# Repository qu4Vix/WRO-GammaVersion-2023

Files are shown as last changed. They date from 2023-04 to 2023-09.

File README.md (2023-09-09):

# WRO 2023 GammaVersion's
**GammaVersion's repo for WRO Future Engineers 2023 season**

***
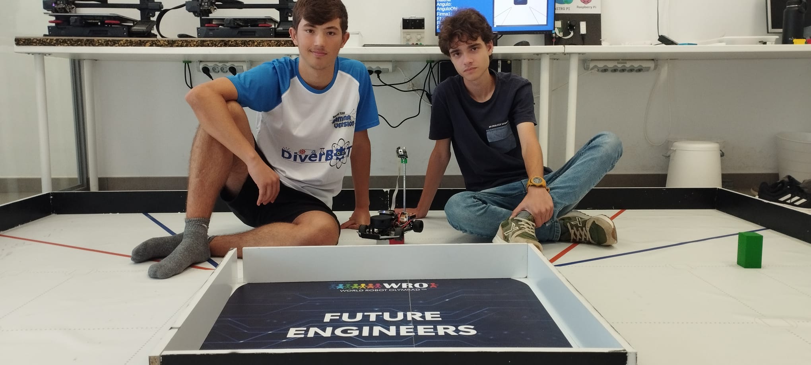
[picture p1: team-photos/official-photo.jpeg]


## Contents

* [Hardware](#hardware)
    * [Components](#component-list)
    * [Models](#models)
    * [Electronics](#electronics)
    * [Ackerman's](#ackerman-steering-geometry)

* [Software](#software)
    * [Sensors](#sensors)
    * [Position](#position)
    * [Strategy](#strategy)

* [Photos](#photos)
    * [Car images](#car-images)
    * [Team images](#team-images)

* [Videos](#videos)
    * [Demonstration videos](#demonstration-videos)

* [Legal](#legal)
    * [License](#license)
    * [Credits](#credits)

***

## Hardware
Building an autonomous car for this challenge involves a meticulous process of reimagining and redesigning various components to achieve precision, safety, and efficiency. In this project, we focused on enhancing the car's steering mechanism, designing a custom-printed circuit board (PCB) to connect all the components seamlessly, and implementing Light Detection and Ranging (LiDAR) technology for superior distance measurement compared to traditional ultrasonic sensors.

### Component List
* **DOIT ESP32 DevKit V1 x2**
* **Pixy 2**
* **RPLIDAR A1 M8**
* **MPU 9250**
* **Pololu Magnetic Encoder**
* **DSM44 Servo**
* **RC Smart Car Chassis Kit** Includes a simple motor
* **Motor Driver x2**
* **Power Supply x3**
* **RGB LEDS**

### Models
**3D-Printed Supports and Structural Parts:**
As a crucial part of our project, we designed and 3D-printed custom supports to secure mechanical components and sensors. These supports ensured precise placement and minimized interference. Additionally, we utilized 3D printing to create lightweight yet robust structural components, allowing us to tailor the car's design to our specific needs while maintaining its strength and adaptability.
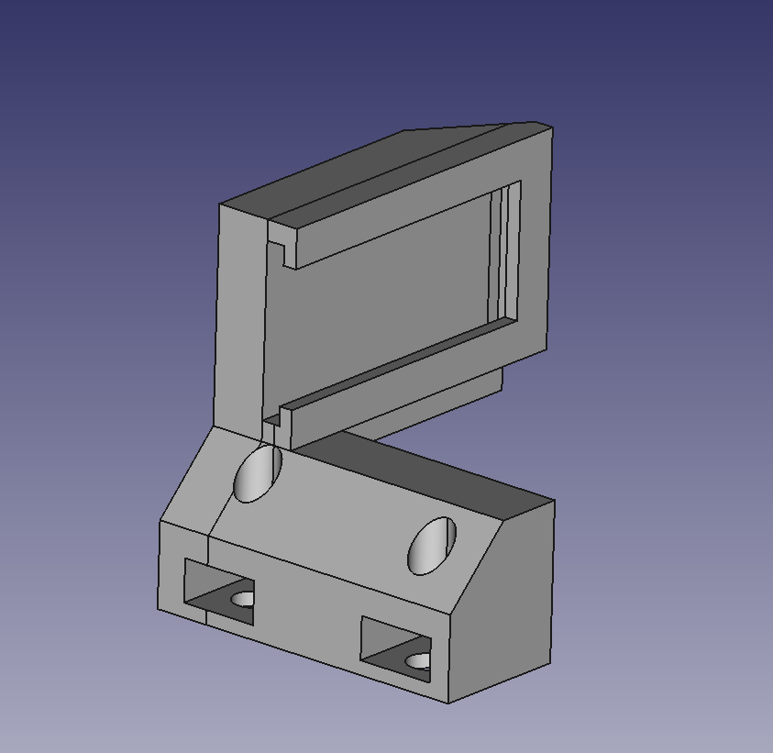
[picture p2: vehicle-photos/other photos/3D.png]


### Electronics
**LiDAR Implementation:**
Rather than relying on traditional ultrasonic sensors for obstacle detection, we opted for LiDAR technology. LiDAR, which stands for Light Detection and Ranging, uses laser beams to measure distances to objects with exceptional precision. This technology offers several advantages over ultrasonic sensors:

a. Greater Range: LiDAR can detect objects at much greater distances, providing the car with more time to react to potential obstacles.

b. High Precision: LiDAR provides accurate distance measurements, resulting in better navigation and collision avoidance.

c. 360-Degree Coverage: LiDAR offers a full 360-degree view around the car, ensuring comprehensive situational awareness.

d. Environmental Adaptability: LiDAR is less affected by environmental factors such as ambient light, making it more reliable in various conditions.
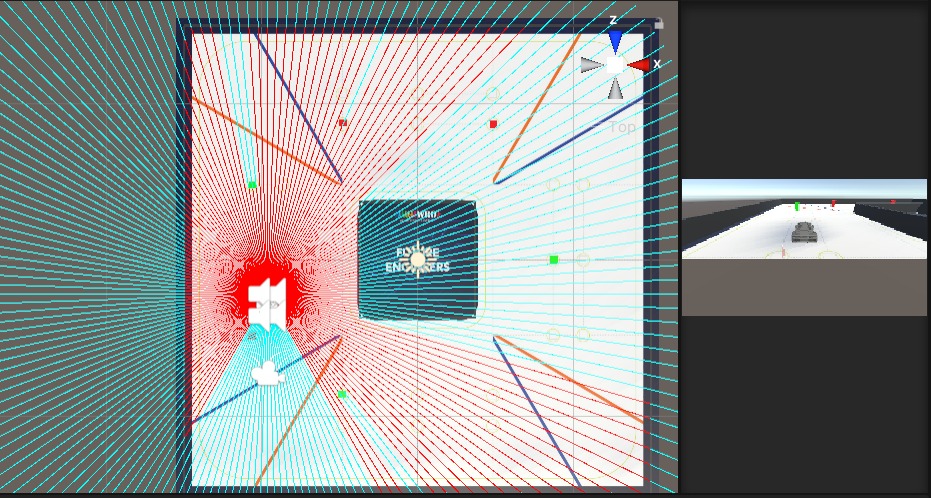
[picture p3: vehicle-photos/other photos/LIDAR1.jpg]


**Esp-32**
To bring our autonomous car project to fruition, we opted for the ESP-32 microcontroller as the central control unit. The ESP-32 boasts several compelling advantages that played a pivotal role in our decision-making process:

1. Computing Power and Versatility: The ESP-32 distinguishes itself with its robust computational capabilities and remarkable versatility. Equipped with a potent dual-core processor and ample memory capacity, it emerged as the natural choice for our robotics endeavor, enabling rapid computation and accommodating our storage needs seamlessly.

2. Advanced Wireless Connectivity: The ESP-32 integrates cutting-edge Wi-Fi and Bluetooth connectivity, positioning it as a frontrunner for efficient wireless communication. This capability empowered us to establish seamless and reliable communication channels between the autonomous car and external devices, such as remote controls or monitoring systems.

3. Sensor and Actuator Compatibility: The ESP-32's adaptability extends to sensor and actuator integration. With its multitude of I/O (input/output) pins and versatile interface options, we effortlessly connected and controlled various sensors, including the IMU and LiDAR, as well as the steering servos.
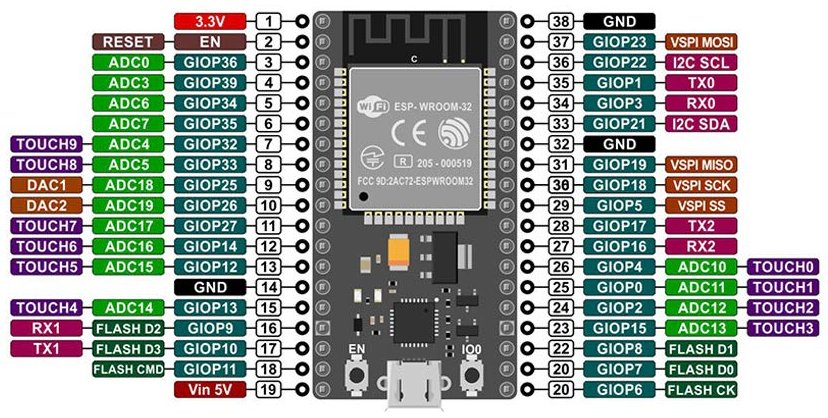
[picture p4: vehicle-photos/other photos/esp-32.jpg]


**Custom PCB Design:**
To seamlessly connect and control all the components of our autonomous car, we designed and printed a custom PCB. The PCB acted as the central hub that allowed us to interface with sensors, motors, microcontrollers, and other electronic components efficiently.

Our custom PCB design allowed for cleaner wiring, reduced interference, and enhanced reliability. It simplified the process of connecting and configuring various sensors and actuators, enabling smoother integration and troubleshooting during the development phase.
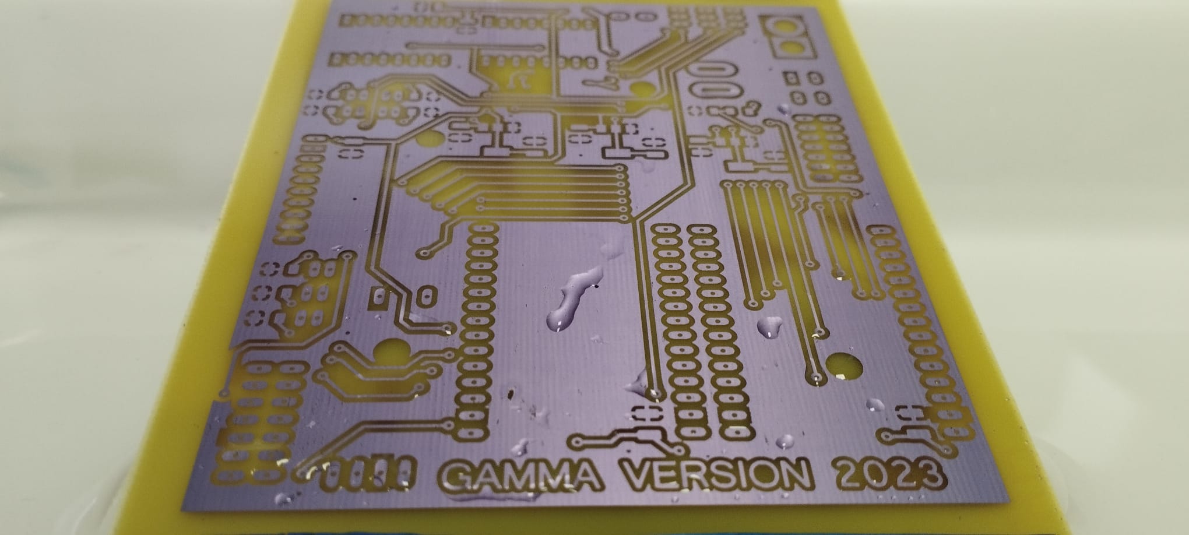
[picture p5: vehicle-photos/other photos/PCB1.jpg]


Our custom-designed PCB played a central role in integrating various components seamlessly. To ensure efficient power management and distribution, we implemented three distinct power sources:

a. Dual 5-Volt Power Supplies: One 5-volt power supply was dedicated to powering the LiDAR system, while the other supplied power to the steering servos. This separation of power sources allowed us to optimize the energy delivery to these critical components, ensuring their reliable operation.
<div calss ="row">
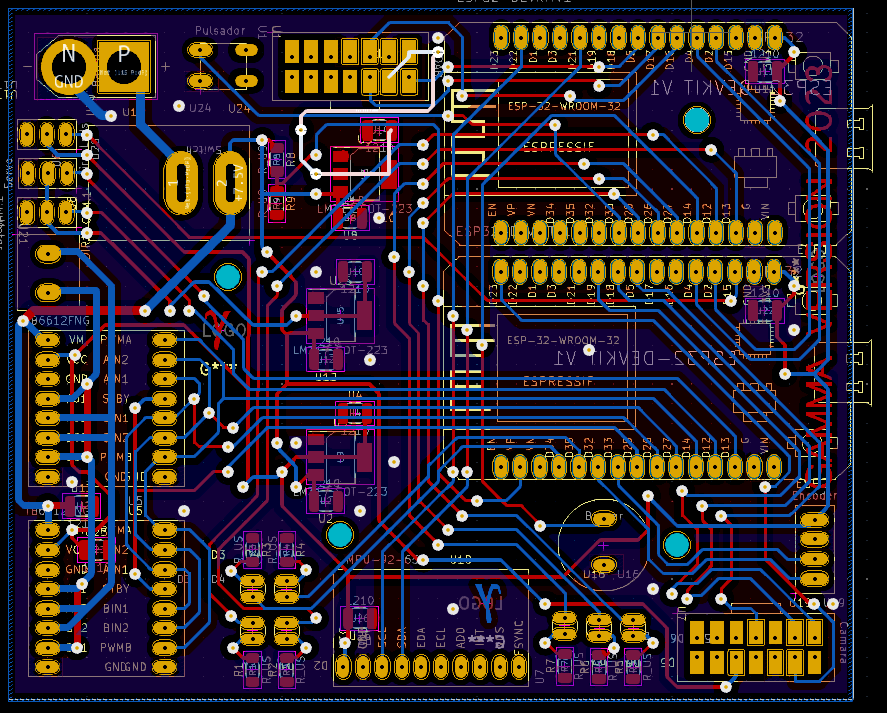
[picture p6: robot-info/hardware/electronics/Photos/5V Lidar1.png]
    
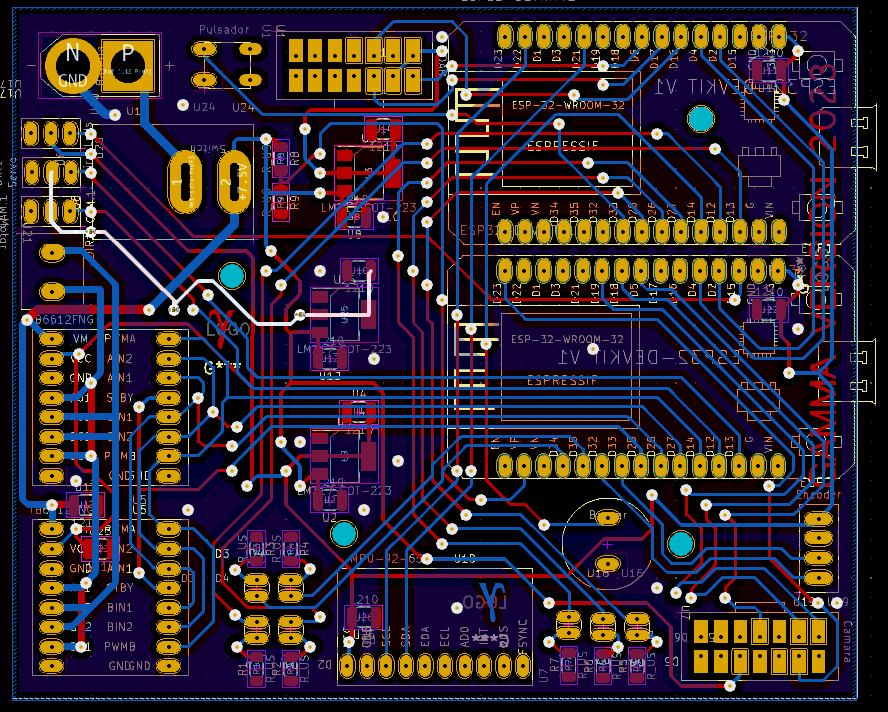
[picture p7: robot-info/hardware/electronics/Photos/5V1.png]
    
</div>

b. 3.3-Volt Power Supply: A dedicated 3.3-volt power supply was employed to energize the microcontrollers, IMU (Inertial Measurement Unit), motor drivers, and LED lights. This voltage level was carefully chosen to meet the requirements of these electronic components, guaranteeing stable and consistent performance.
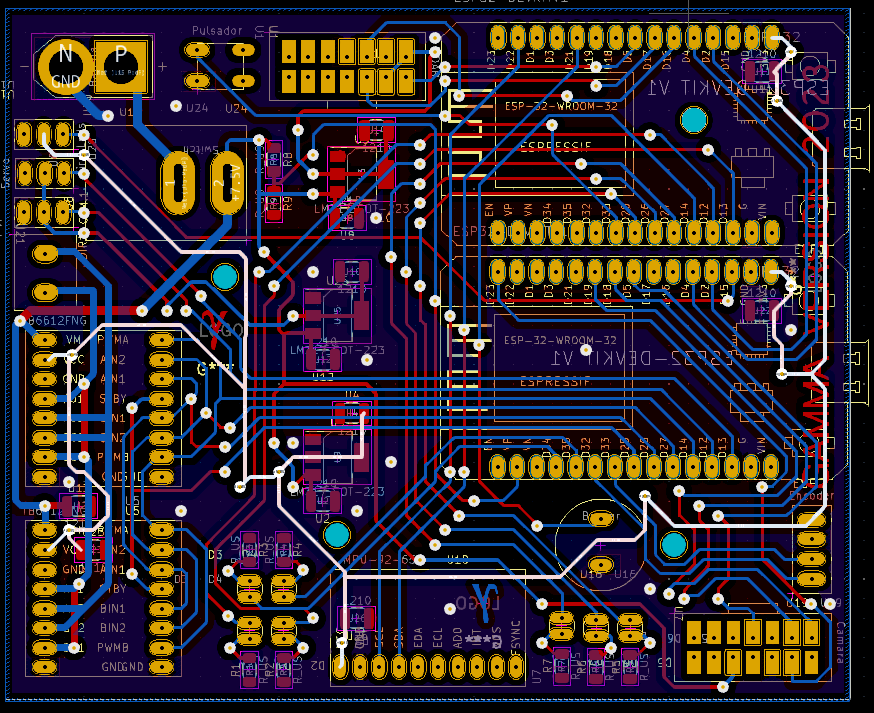
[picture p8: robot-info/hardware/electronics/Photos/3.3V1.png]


By employing these distinct power sources, we effectively managed the power needs of our autonomous car's various subsystems, ensuring that each component received the appropriate voltage and current for reliable operation. This meticulous power management contributed to the overall success and stability of our robotics project.

### Ackerman's Steering Geometry
One of the key aspects of our project was reimagining the steering system to achieve a reduced turn ratio. To accomplish this, we implemented Ackermann steering geometry. Ackermann steering geometry is a mechanism that ensures that all four wheels of the car track along different paths during a turn, reducing tire wear and enabling smoother and more precise turns.

By incorporating Ackermann steering, we were able to optimize the car's turning radius, allowing it to navigate tighter corners with ease. This was achieved by adjusting the angles of the wheels and their pivot points, ensuring that the inner and outer wheels followed distinct paths, greatly enhancing the car's maneuverability.
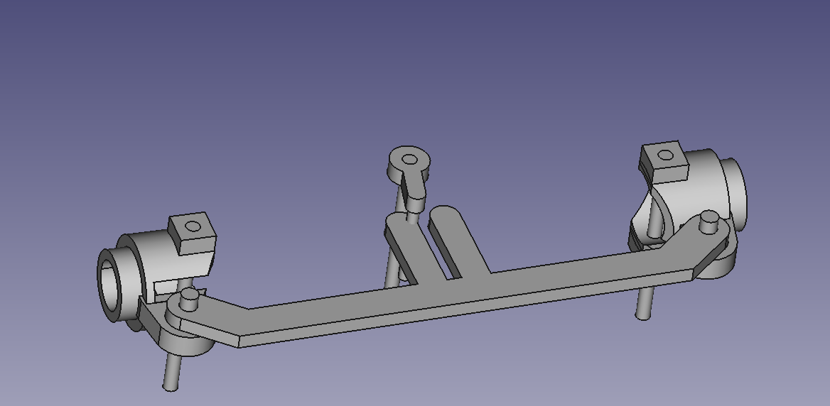
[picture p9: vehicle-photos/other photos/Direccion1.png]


***

## Software

### Sensors
* **MPU:** We use the MPU's GyroScope functionality to measure the angular speed along the Z-axis. Integrating this speed over time we get the orientation of the car.
* **Encoder:** The encoder allows us to know the displacement of the car and consequently its speed, which we regulate using a PID controller.
* **LIDAR:** The LIDAR sensor measures distances on a 360º range, therefore it allows the car to have a great knowledge of the surroundings. We store all the readings in an array when they are received.
* **Pixy 2:** Pixy is an intelligent camera which can identify regions with the same colour. As a result, our code to handle the detection of the traffic lights is very reduced. 

### Position
With the data of the orientation and the displacement of the car we are able to calculate the position of the car. This is worked out by integrating the displacement over the trajectory of the car. With these calculations the coordiante origin is set to the initial position of the car, but we change it to the bottom left corner of the playfield with the measures of the LIDAR.

### Strategy
Our strategy is to make the car able to define a path for the it to follow depending on the colour blocks it detects. We devide the playfield into eight sections, and the car stores whether it has to travel to the right or to the left in each section.

***

## Photos

### Car images
| | |
| --- | --- |
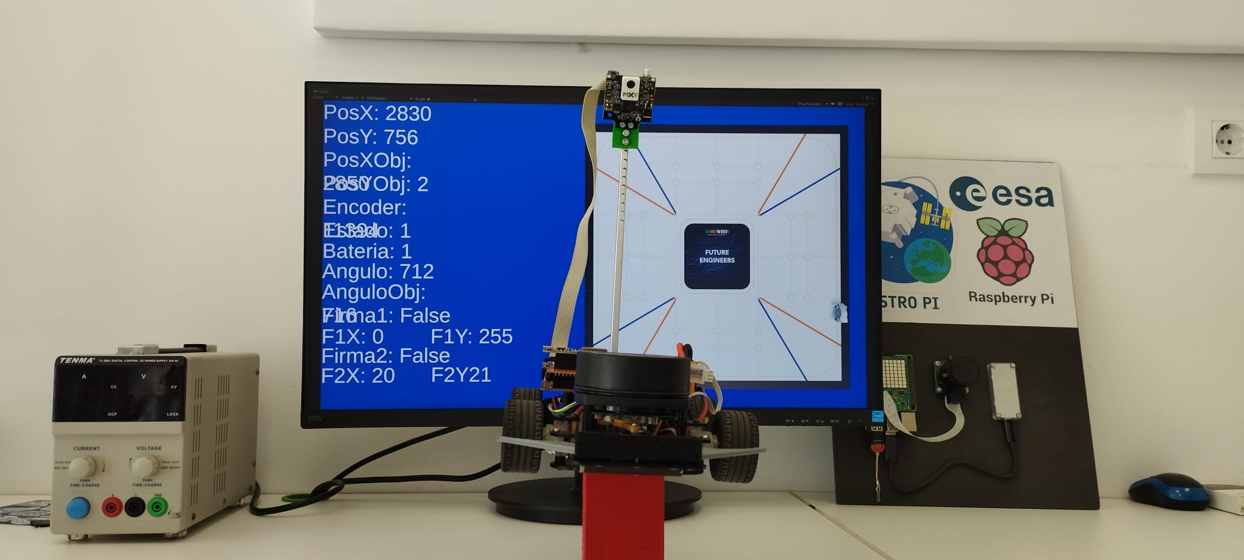
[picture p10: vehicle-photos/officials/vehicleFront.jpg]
front
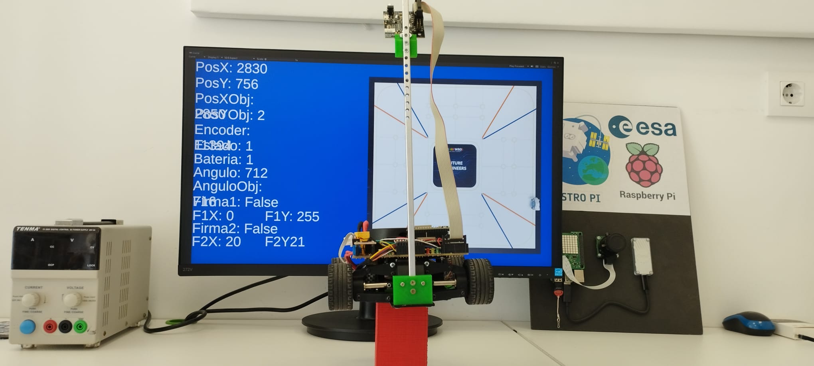
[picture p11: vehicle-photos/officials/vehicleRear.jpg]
back
|  |  |
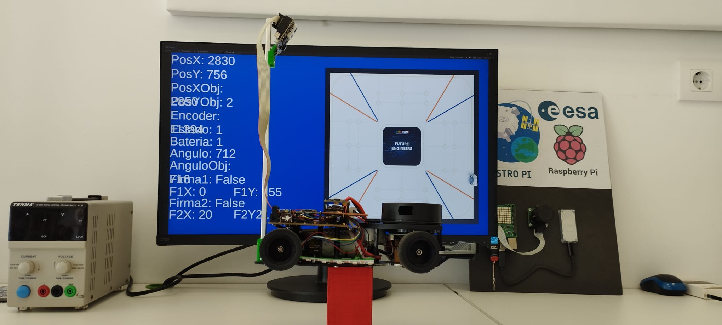
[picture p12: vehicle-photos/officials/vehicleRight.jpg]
right
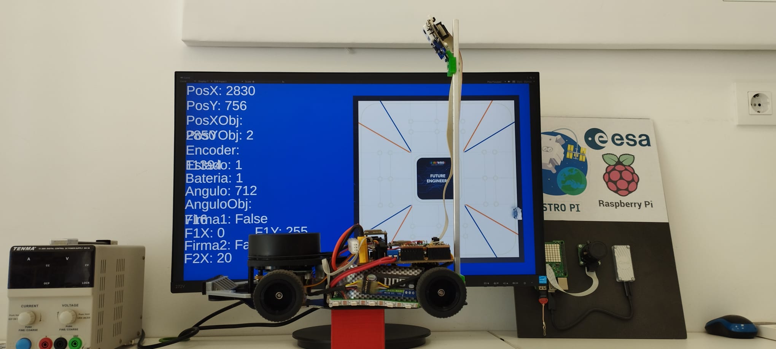
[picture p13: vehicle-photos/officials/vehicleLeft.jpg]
left
|  |  |
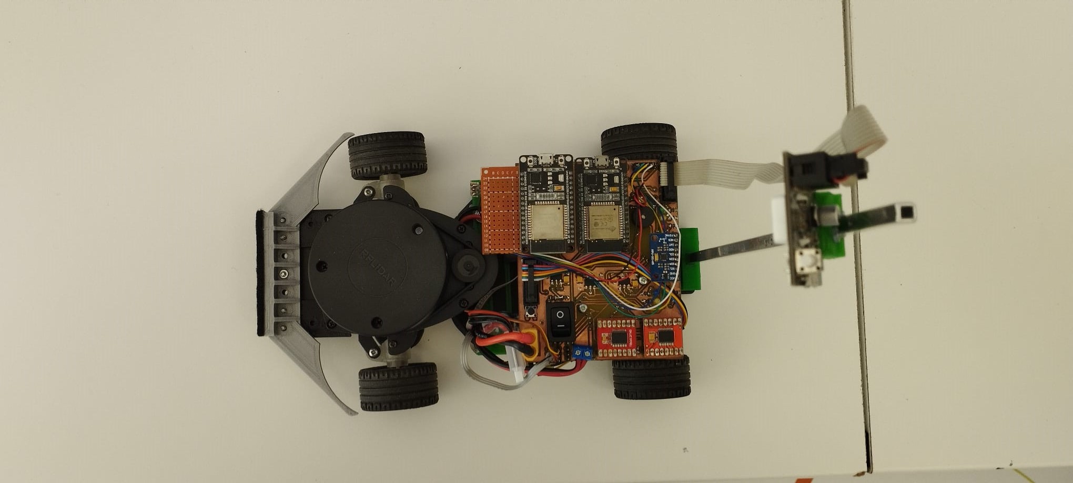
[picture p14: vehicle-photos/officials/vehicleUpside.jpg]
top
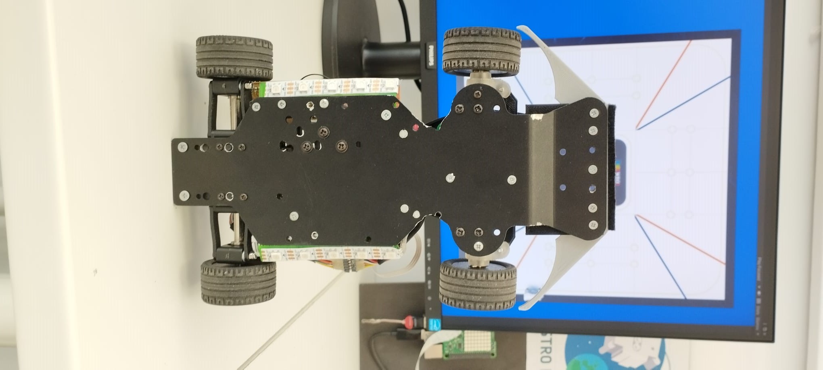
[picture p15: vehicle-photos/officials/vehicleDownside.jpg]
bottom
|  |  |

### Team images
| | |
| --- | --- |
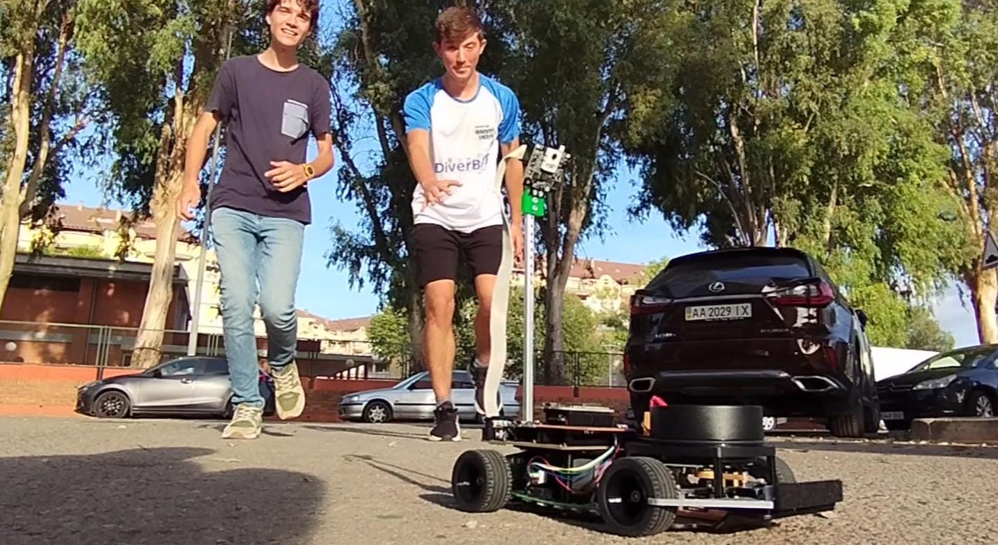
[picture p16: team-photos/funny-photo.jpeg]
funny
| official |  |

***

## Videos

### Demonstration videos

Demonstration videos of the car successfully completing both challenges.
The links to each of them can be found in:
* [Open Challenge](https://youtu.be/Oyp9x_MhnpQ?si=n7GRa3e0AN-YdxIk)
* [Obstacle Challenge](https://youtu.be/bCaAXYcNQ1c)

***

## Legal

### License

The [source code](/code/) in this repository is licensed under the **GNU General Public License v3.0**.

The [hardware](/robot-info/hardware/) exposed in this project is licensed under the **Creative Commons Attribution Share Alike 4.0 International** license.

The documentation of this repository; found in [`robot-info`](/robot-info/), [`vehicle-photos`](/vehicle-photos/), [`videos`](/videos/), [`team-photos`](/team-photos/), as well as this `README.md`; is licensed under the **CERN Open Hardware Licence Version 2 - Strongly Reciprocal** license.

A copy of each license can be found in the [LICENSE](LICENSE) file. More information about the licenses in the specific README.md of each section.

### Credits

***

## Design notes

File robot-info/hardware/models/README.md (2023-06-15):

### Models
In this folder you can find all the models used in our robot. All of them designed by us using Freecad.
***
### Supports
In the [supports](/supports/) folder, you can find all the supports made for hold diferent parts of the robot, such as sensors or the PCB.
***
### Steering
And the [steering](/steering/) folder, contains all the models used for the new steering system designed specialy for increase the steering angle.
***
### Freecad files
All the models are in .stl format, wich have large compatibility with 3d modeling progras and printing software. Also you have a Freecad folder in the [Supports](/supports/FreecadFiles/) and [Steering](/steering/FreecadFiles/) folders, in wich you can find the files to open in Freecad and edit easily all the models.

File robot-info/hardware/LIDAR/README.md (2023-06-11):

# LIDAR
## Explanatory directory for the LIDAR component

The [`frame_grabber.exe`](frame_grabber.exe) file is a testing program made by Slamtec with GPLv3 license which can be found in their [GitHub](https://github.com/Slamtec/rplidar_sdk) . No changes have been done to this file.

### Cable Color Code
- Yellow - TX
- Green - RX
- Orange - VCC
- White - GND
- Black - GND_Motor
- Blue - CTRL_Motor
- Red - 5V_Motor

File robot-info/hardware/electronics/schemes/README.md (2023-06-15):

## Schemes
### Folder Content
* **Union Diagram**: [This file](/UnionSchematic.pdf/), provides a graphical representation of all the necessary connections to properly assemble the robot. The union diagram will help you understand how the different components are connected and ensure that everything is properly interconnected.

* **Electrical Schematic**: [In this file](/PCBSchematic.pdf) you will find a detailed electrical diagram of the robot. This diagram provides a visual representation of how electrical components such as motors, sensors, microcontrollers, and power sources are connected. The electrical schematic is essential to understand how electrical current is distributed and flows within the robot.

***

### File format
All the files are in PDF format to ensure accurate and accessible viewing on different platforms and devices. You can use a PDF viewer to open and examine the diagrams in detail.

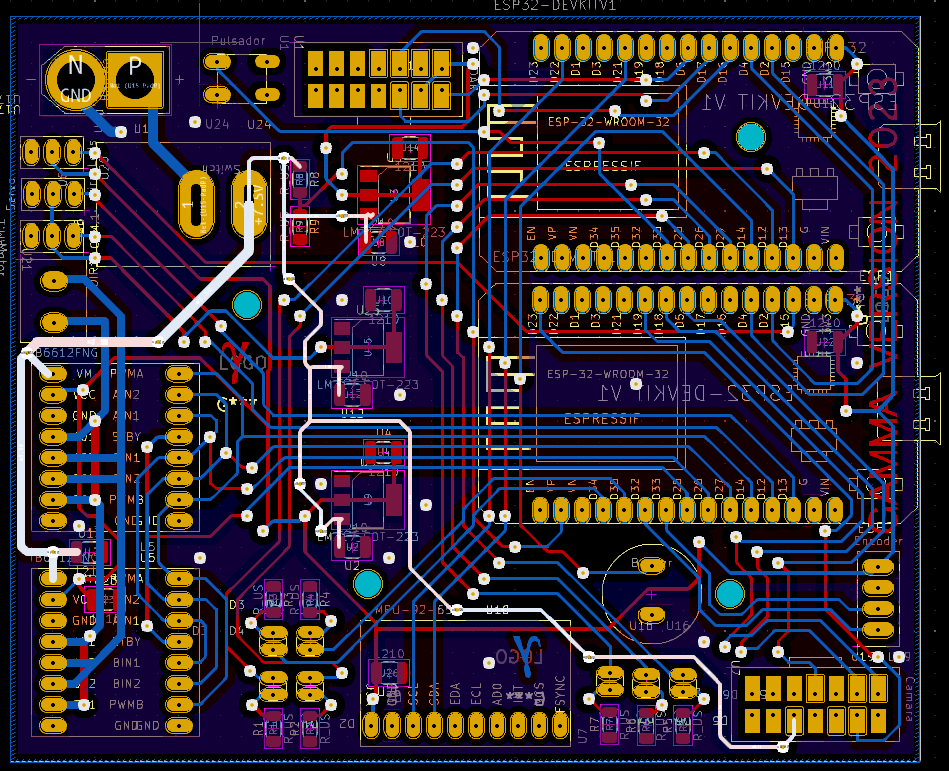
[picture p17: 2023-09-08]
robot-info/hardware/electronics/Photos/7V1.png

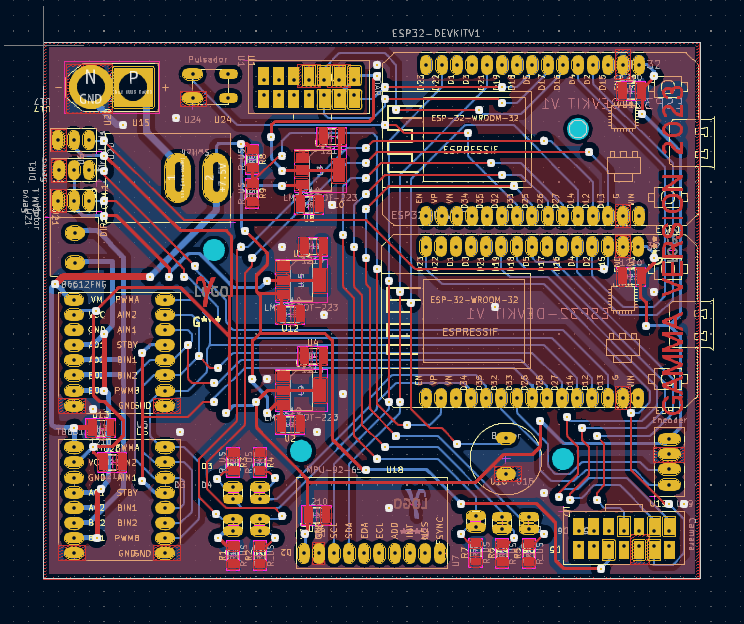
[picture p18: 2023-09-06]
robot-info/hardware/electronics/Photos/AllLayers.png

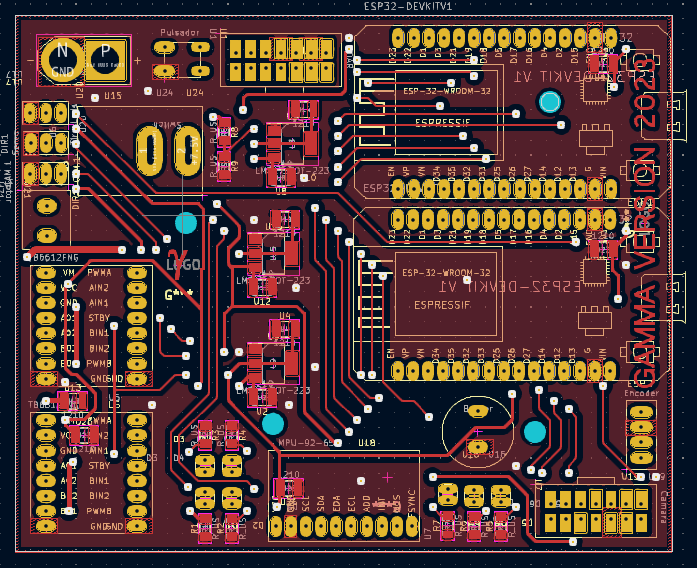
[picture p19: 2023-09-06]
robot-info/hardware/electronics/Photos/Layer1.png

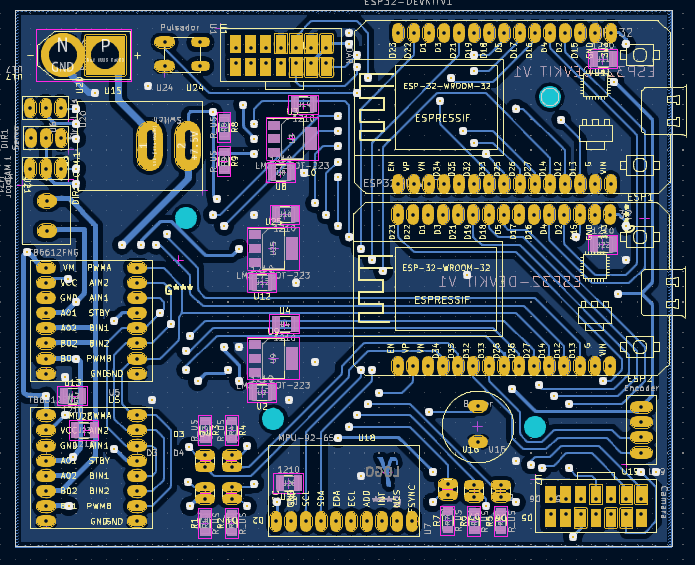
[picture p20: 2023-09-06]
robot-info/hardware/electronics/Photos/Layer2.png

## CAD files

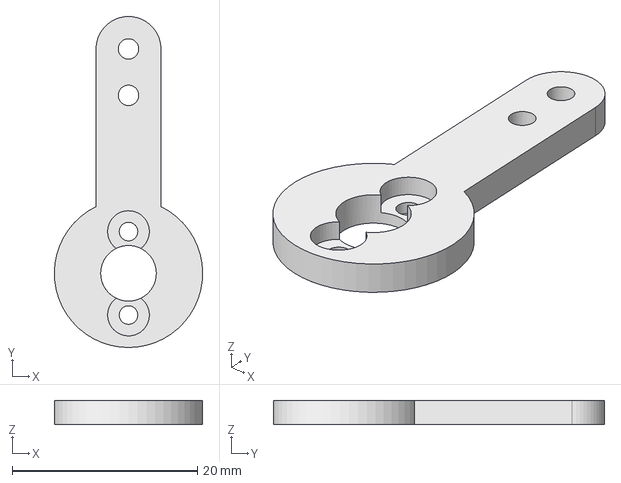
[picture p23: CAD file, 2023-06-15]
robot-info/hardware/models/steering/FreecadFiles/ServoArm.FCStd
16.0 x 35.7 x 2.60 mm

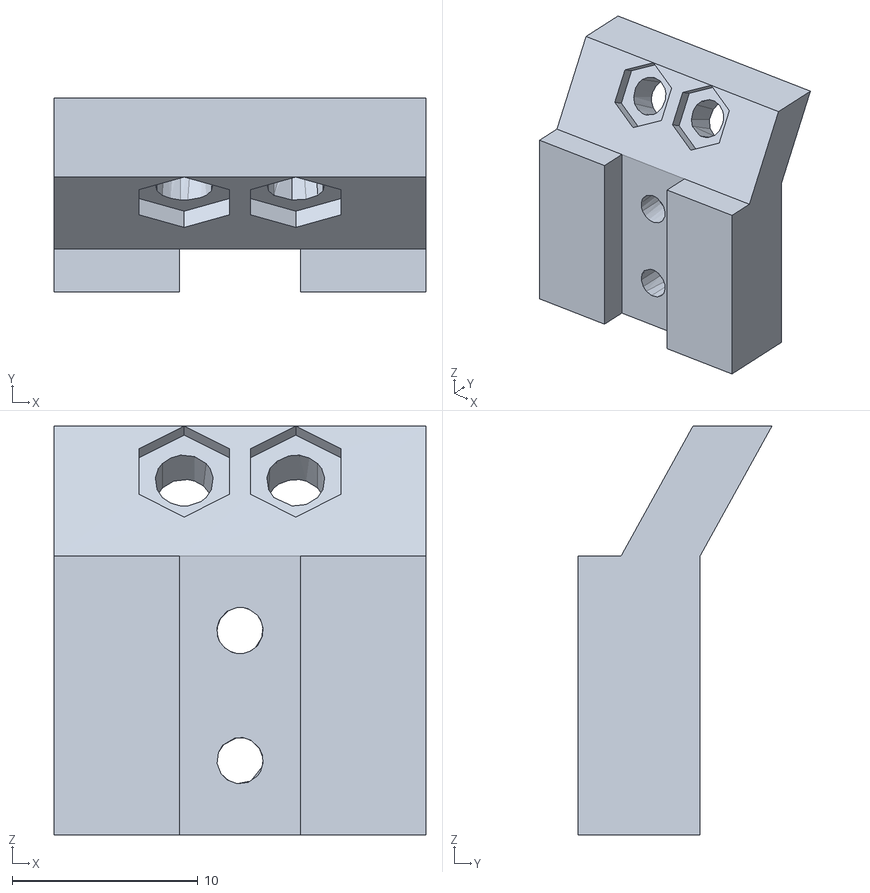
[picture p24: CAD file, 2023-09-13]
robot-info/hardware/models/supports/CameraSupport.stl
20.0 x 10.4 x 22.0

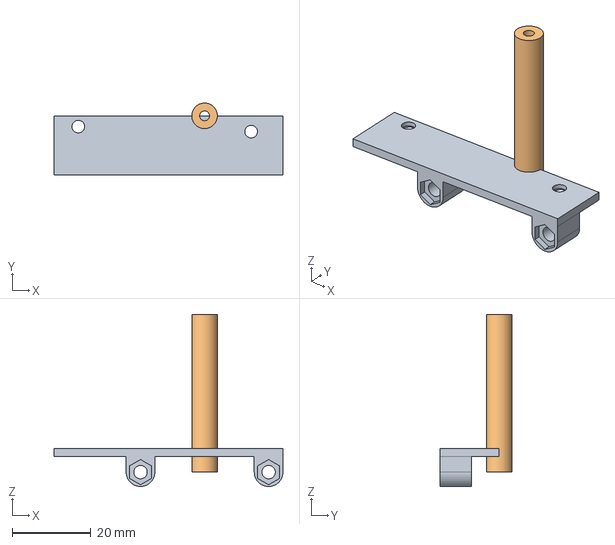
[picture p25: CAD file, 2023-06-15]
robot-info/hardware/models/supports/FreecadFiles/PcbSupports.FCStd
58.1 x 18.2 x 43.7 mm
Trasero
Delantero

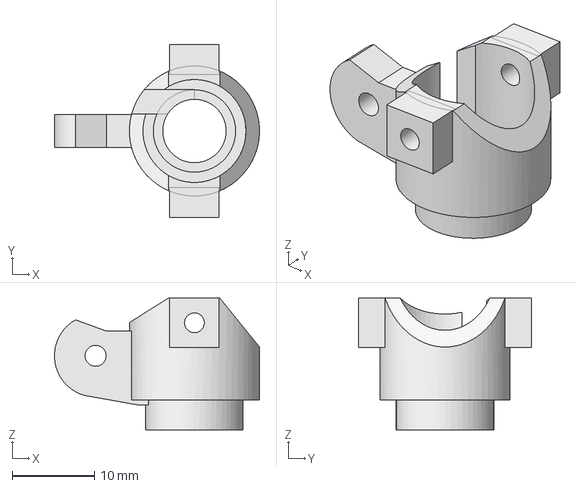
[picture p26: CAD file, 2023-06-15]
robot-info/hardware/models/steering/FreecadFiles/WheelHook.FCStd
24.9 x 21.0 x 16.0 mm

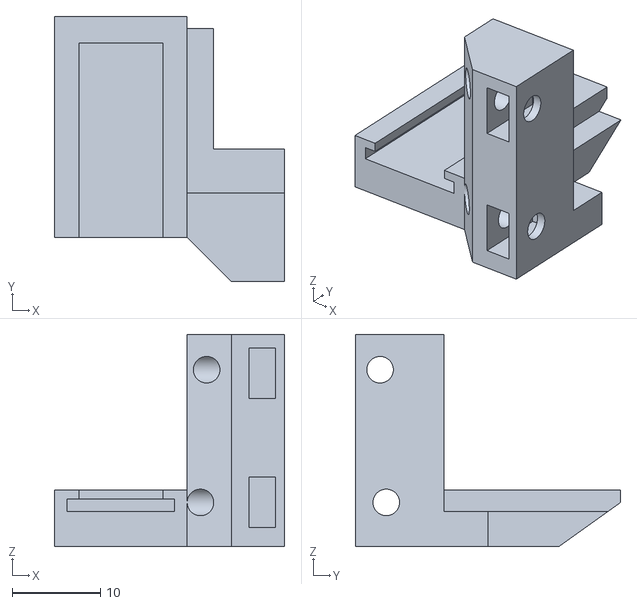
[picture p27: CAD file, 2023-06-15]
robot-info/hardware/models/supports/EncoderSupport-Base.stl
26.0 x 30.0 x 24.0

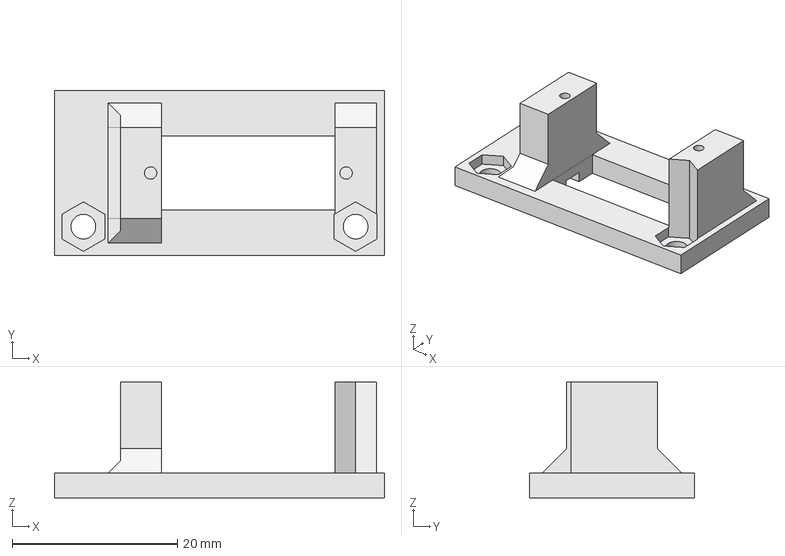
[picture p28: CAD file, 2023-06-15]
robot-info/hardware/models/supports/FreecadFiles/ServoSupport.FCStd
40.0 x 20.0 x 14.1 mm

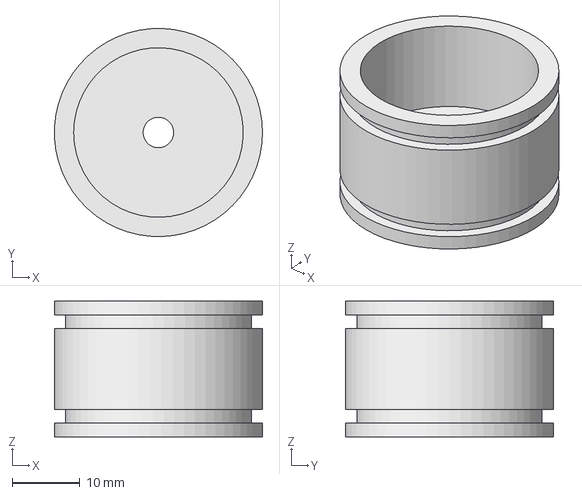
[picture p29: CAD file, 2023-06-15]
robot-info/hardware/models/steering/FreecadFiles/Wheel.FCStd
30.7 x 30.7 x 20.0 mm

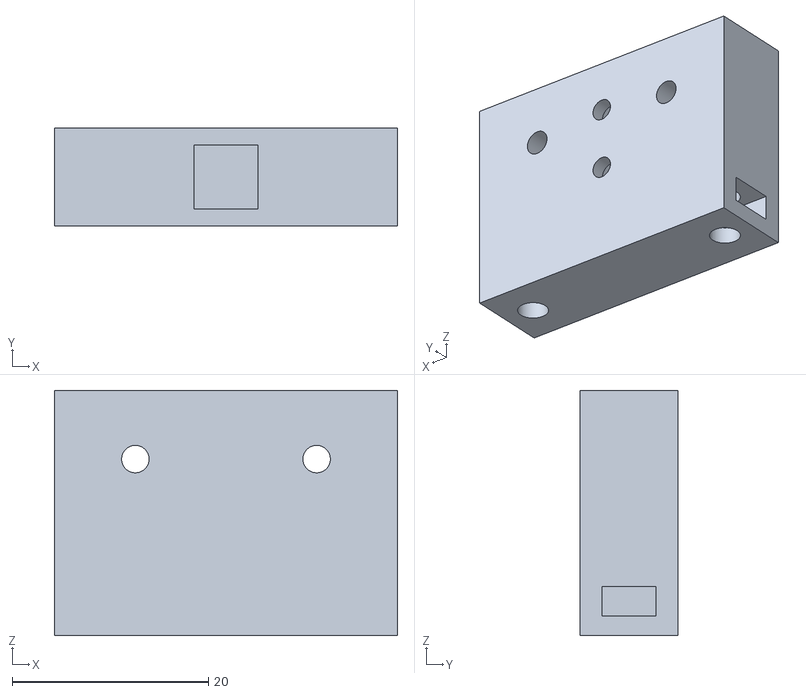
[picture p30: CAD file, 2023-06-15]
robot-info/hardware/models/supports/CameraSupport-Base.stl
35.0 x 10.0 x 25.0

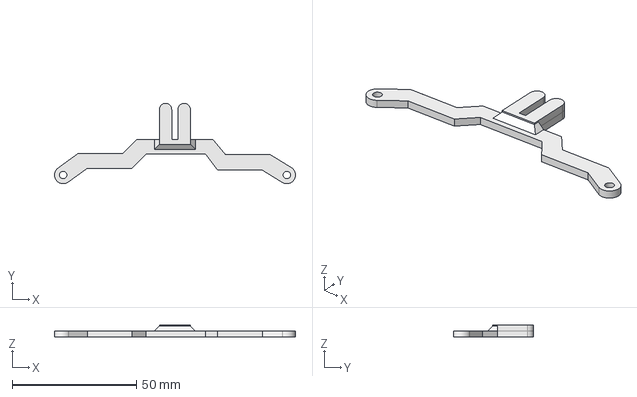
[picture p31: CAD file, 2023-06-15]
robot-info/hardware/models/steering/FreecadFiles/SteeringArm.FCStd
97.0 x 32.4 x 5.00 mm

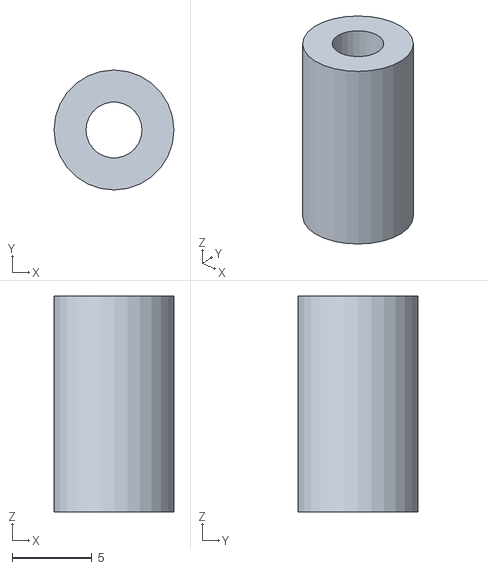
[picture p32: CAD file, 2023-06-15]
robot-info/hardware/models/supports/LidarSupport-Back.stl
7.50 x 7.50 x 13.5

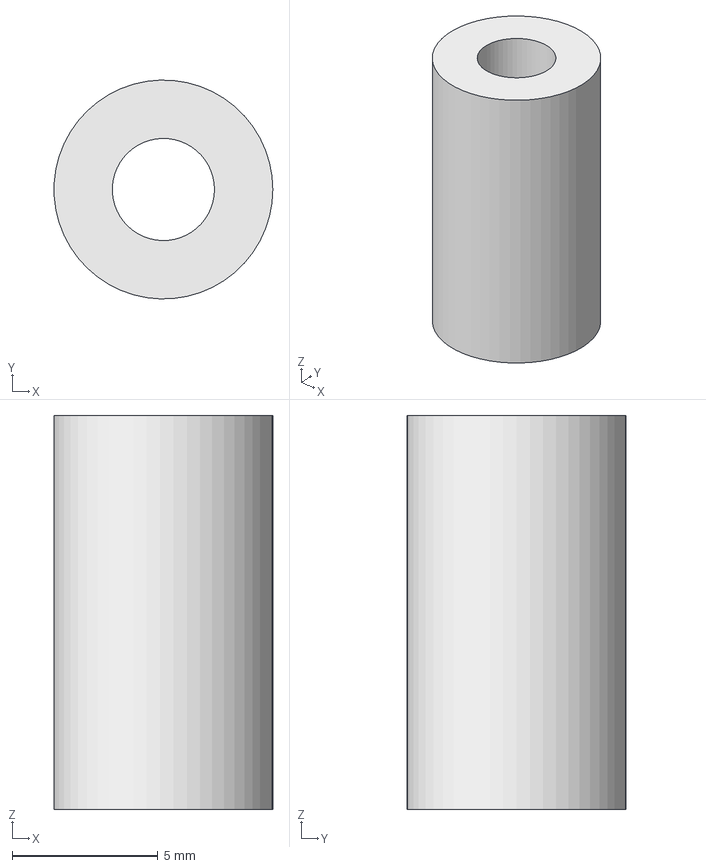
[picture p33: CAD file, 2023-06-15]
robot-info/hardware/models/supports/FreecadFiles/LidarSupports.FCStd
7.49 x 7.50 x 13.5 mm

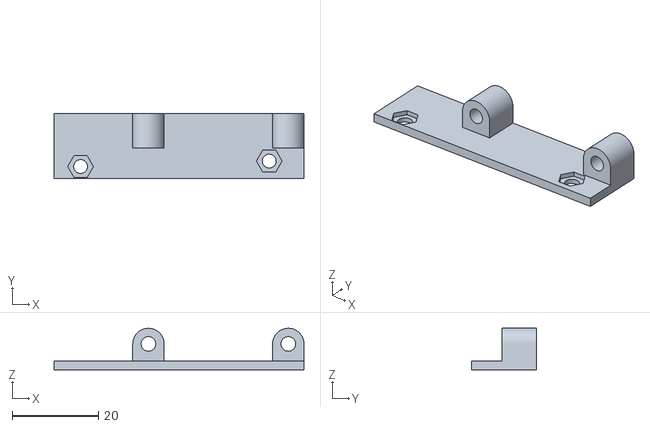
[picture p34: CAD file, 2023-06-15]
robot-info/hardware/models/supports/PcbSupport-Back.stl
58.1 x 15.0 x 9.65

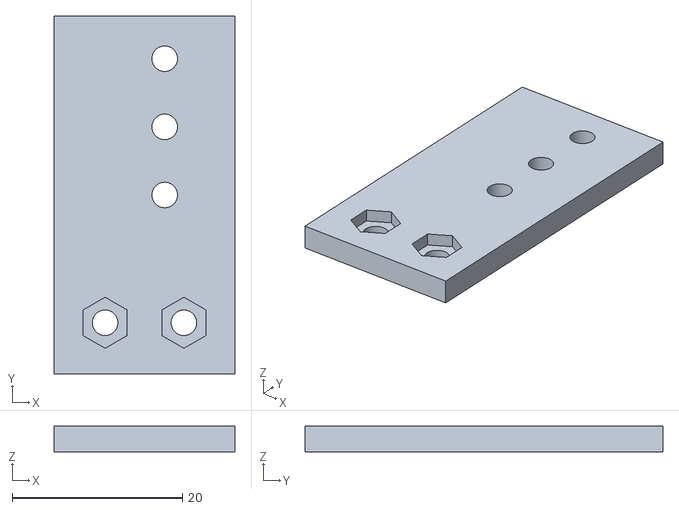
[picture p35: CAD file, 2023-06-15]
robot-info/hardware/models/supports/LidarSupport-Front.stl
21.2 x 42.0 x 3.00

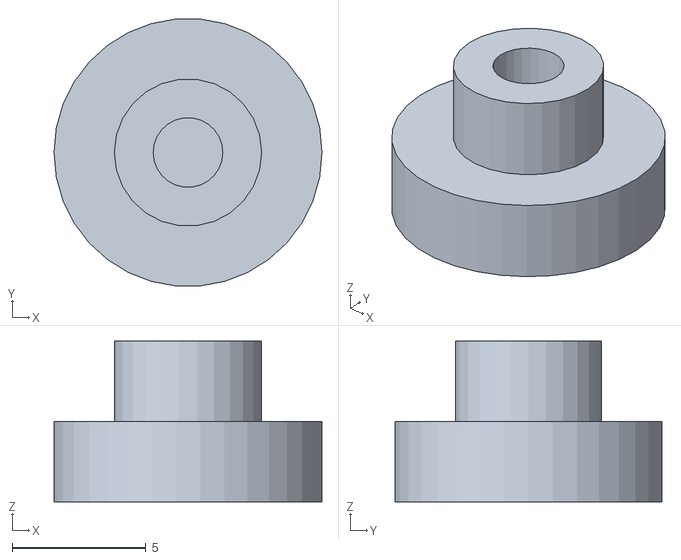
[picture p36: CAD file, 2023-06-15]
robot-info/hardware/models/supports/EncoderSupport-Axis.stl
10.0 x 9.96 x 6.00

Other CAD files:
robot-info/hardware/models/supports/FreecadFiles/CameraSupports.FCStd
robot-info/hardware/models/supports/FreecadFiles/EncoderSupports.FCStd
robot-info/hardware/models/supports/PcbSupport-Front.stl
robot-info/hardware/models/steering/ServoArm.stl
robot-info/hardware/models/steering/SteeringArm.stl
robot-info/hardware/models/steering/Wheel.stl
robot-info/hardware/models/steering/WheelHook.stl
robot-info/hardware/models/supports/ServoSupport.stl

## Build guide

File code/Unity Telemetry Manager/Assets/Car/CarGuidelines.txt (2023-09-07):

In the Car folder you'll find a few ready-made Car prefabs, which are used in the Car sample scenes. These prefabs demonstrate how you can use the Car scripts we've included, including some AI-controlled variants which are able to drive directly towards a specified target, or follow a waypoint-based route.

The scripts included have been designed to be modular in nature, so that the extra features of a particular car can be set up (such as brake lights, engine sound, and skid trails).

The simplest way to get started setting up your own car is to use our "CarPrefabEmpty", and to follow these steps:

1) Start with a suitable scene. There ought to be enough flat ground to drive around on.

2) Place the "CarPrefabEmpty" in the scene.

3) Place your 3d model into the scene, as a child of the "CarPrefabEmpty" GameObject. Notice that your car model should be at the same level as the "WheelHub" objects that were already present.

4) Make sure your car's position in the inspector is set to 0,0,0. This will ensure your car's position is aligned with the Empty Prefab's position.

5) Expand the hierarchy of your car model in the hierarchy so that the wheel models of your car are visible.

6) Select each "WheelHub" in turn, and drag the corresponding wheel model from your car into the "Wheel Model" slot of the Wheel component on the WheelHub GameObject. Then click the "Align to assigned wheel model". If your car has four wheels, you'll need to do this step four times, once for each wheel. 

7) Hit play, and try driving your car!

You'll probably want to add a camera rig so that the camera follows the car as it drives off. See the Camera Rig guidelines for instructions on how to do that.

The Car script exposes a number of properties which determine the power, maximum speed, and handling of the car, however ultimately the script is designed to provide a fun arcade game-like feel rather than attempting to be a realistic simulation of car handling. The gears and revs values are purely cosmetic, and are calculated retrospectively - they can be used by the engine sound component or GUI to display revs and gear.

For more detail about each setting, see the comments in the script.

The CarUserControl script takes input from the "CrossPlatformInput" class included in the sample assets, however if you're not targeting mobile or prefer to use a different system to read input, you can simply use unity's built in Input class in place of CrossPlatformInput. For more information, see the Cross Platform Input guidelines.

The sample scenes provided work on standalone builds and also include cross platform touch and tilt controls which are set up and ready to publish to mobile. 

The CarAIControl component can be added instead of the CarUserControl component, allowing the car to be AI controlled. You can set it up to either head towards a specified target, or (by using the WaypointProgressTracker) follow a waypoint-defined route. See the WaypointCircuit guidelines for instructions.

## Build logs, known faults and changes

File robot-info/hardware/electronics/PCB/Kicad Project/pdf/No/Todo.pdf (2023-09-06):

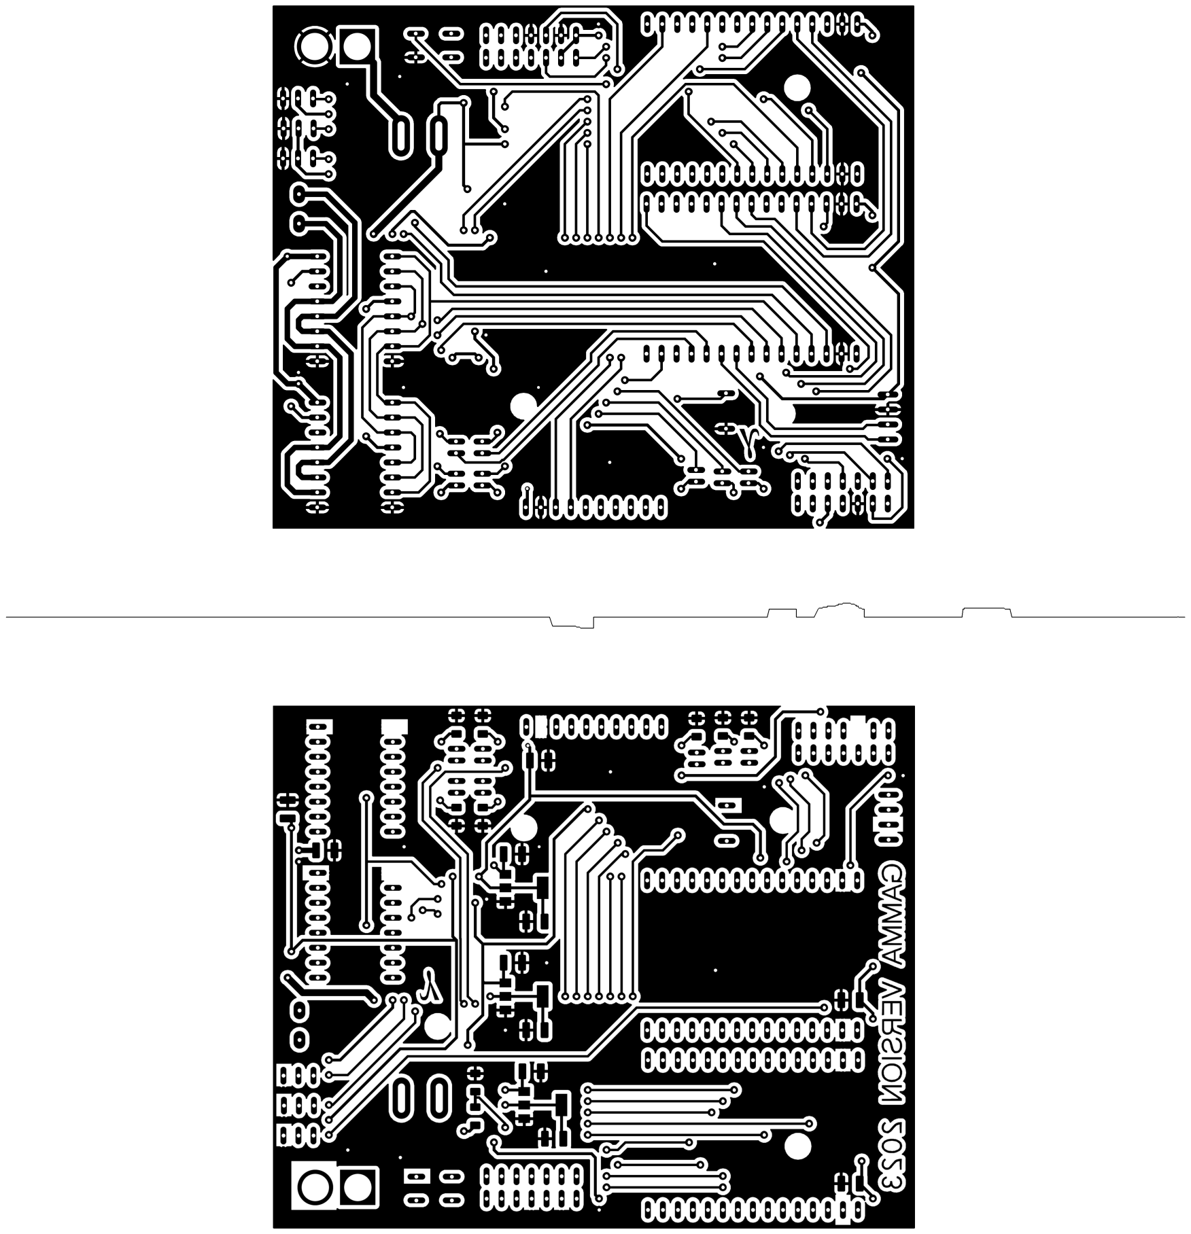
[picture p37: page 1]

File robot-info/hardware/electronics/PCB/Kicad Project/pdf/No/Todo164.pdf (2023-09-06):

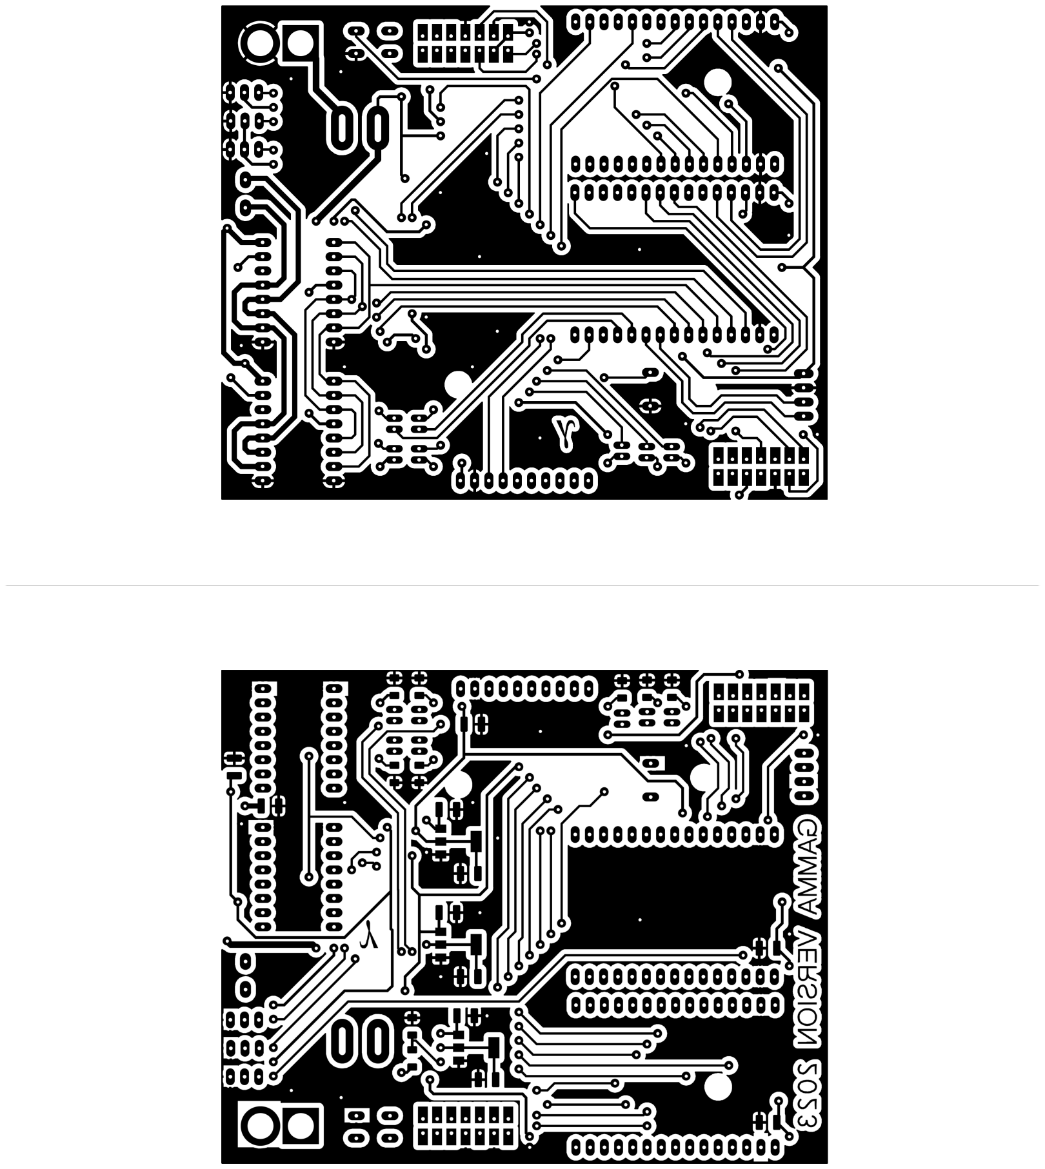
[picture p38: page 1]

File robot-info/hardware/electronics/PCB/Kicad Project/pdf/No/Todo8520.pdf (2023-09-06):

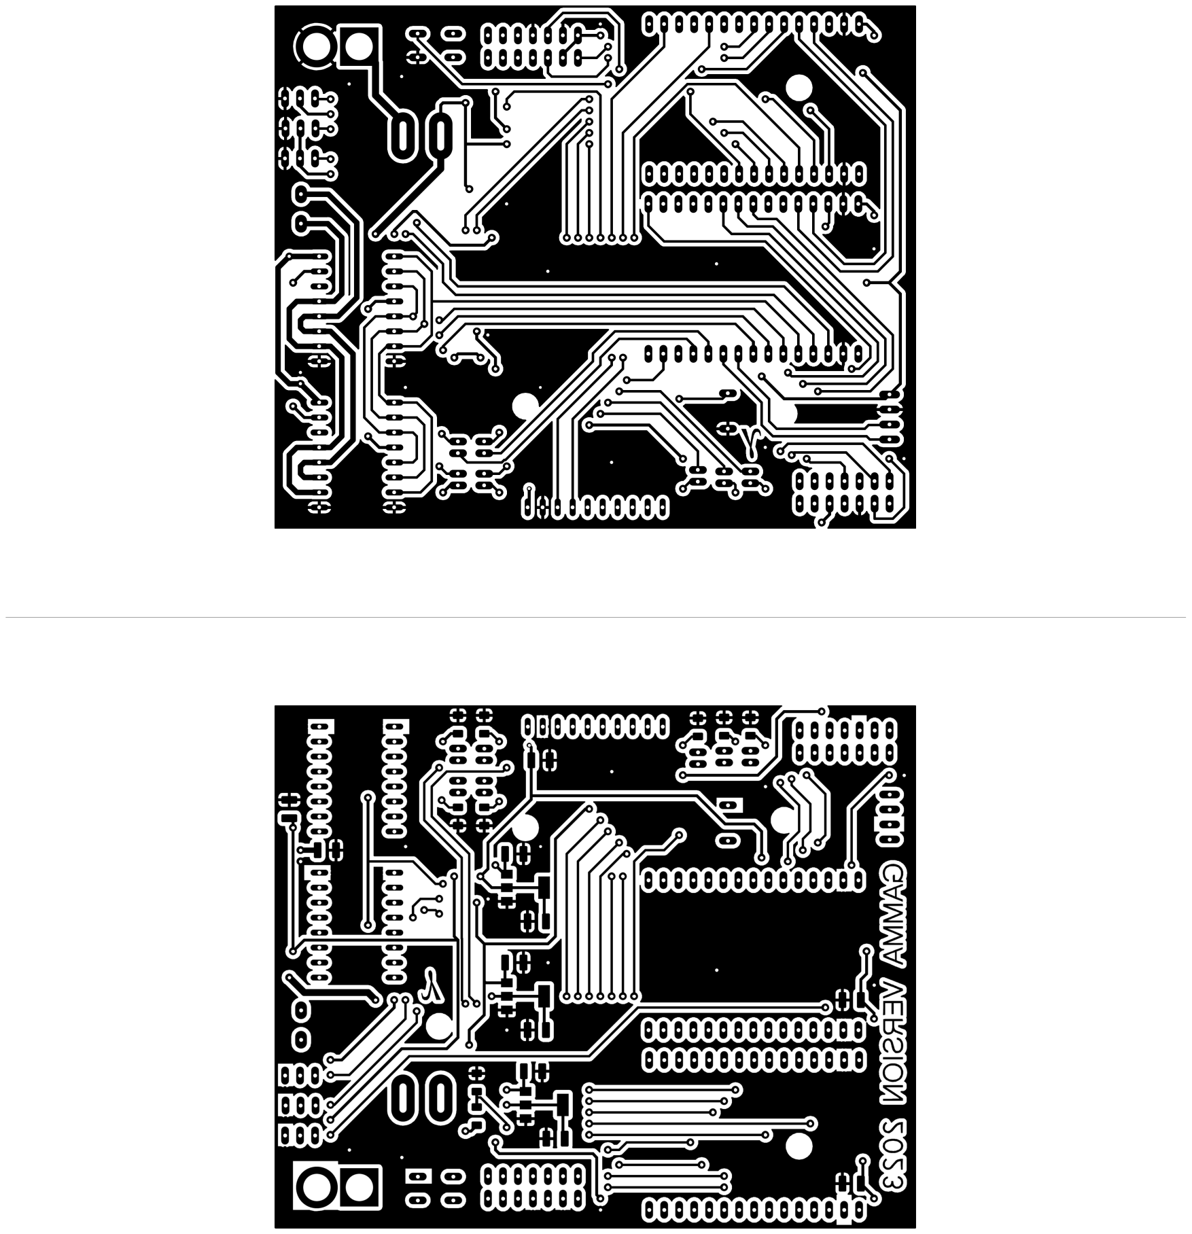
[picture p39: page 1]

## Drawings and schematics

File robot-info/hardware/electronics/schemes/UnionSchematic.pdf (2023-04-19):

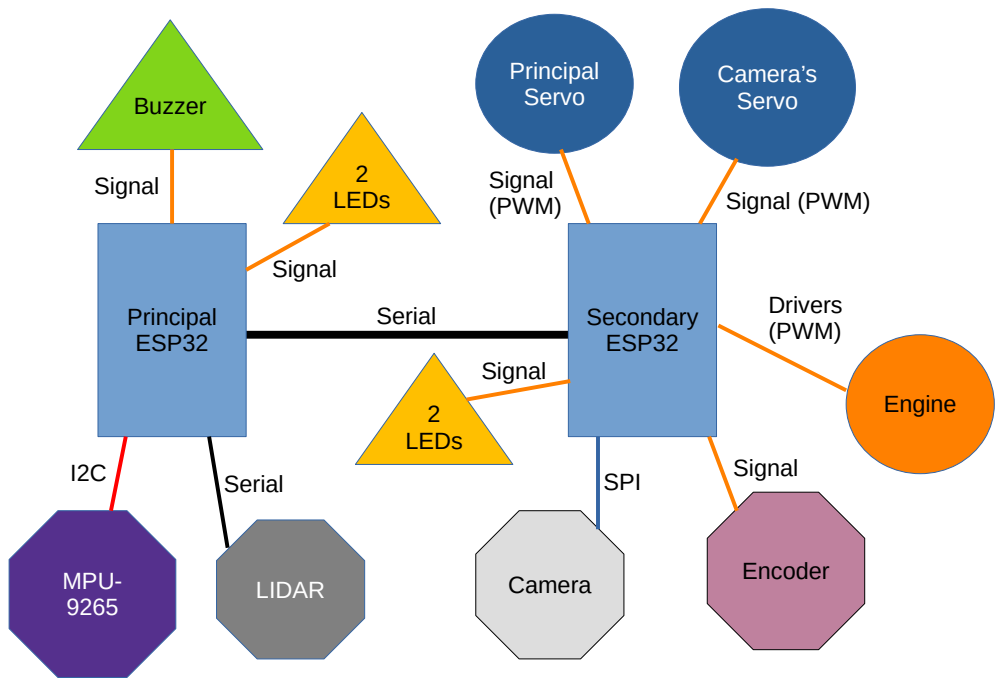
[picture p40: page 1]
Serial; Secondary; ESP32; Principal ESP32; Engine; Camera’s Servo; Principal Servo; Camera; Encoder MPU-; LIDAR; 2 LEDs; Buzzer; SPI; Signal; Signal (PWM); Drivers (PWM)

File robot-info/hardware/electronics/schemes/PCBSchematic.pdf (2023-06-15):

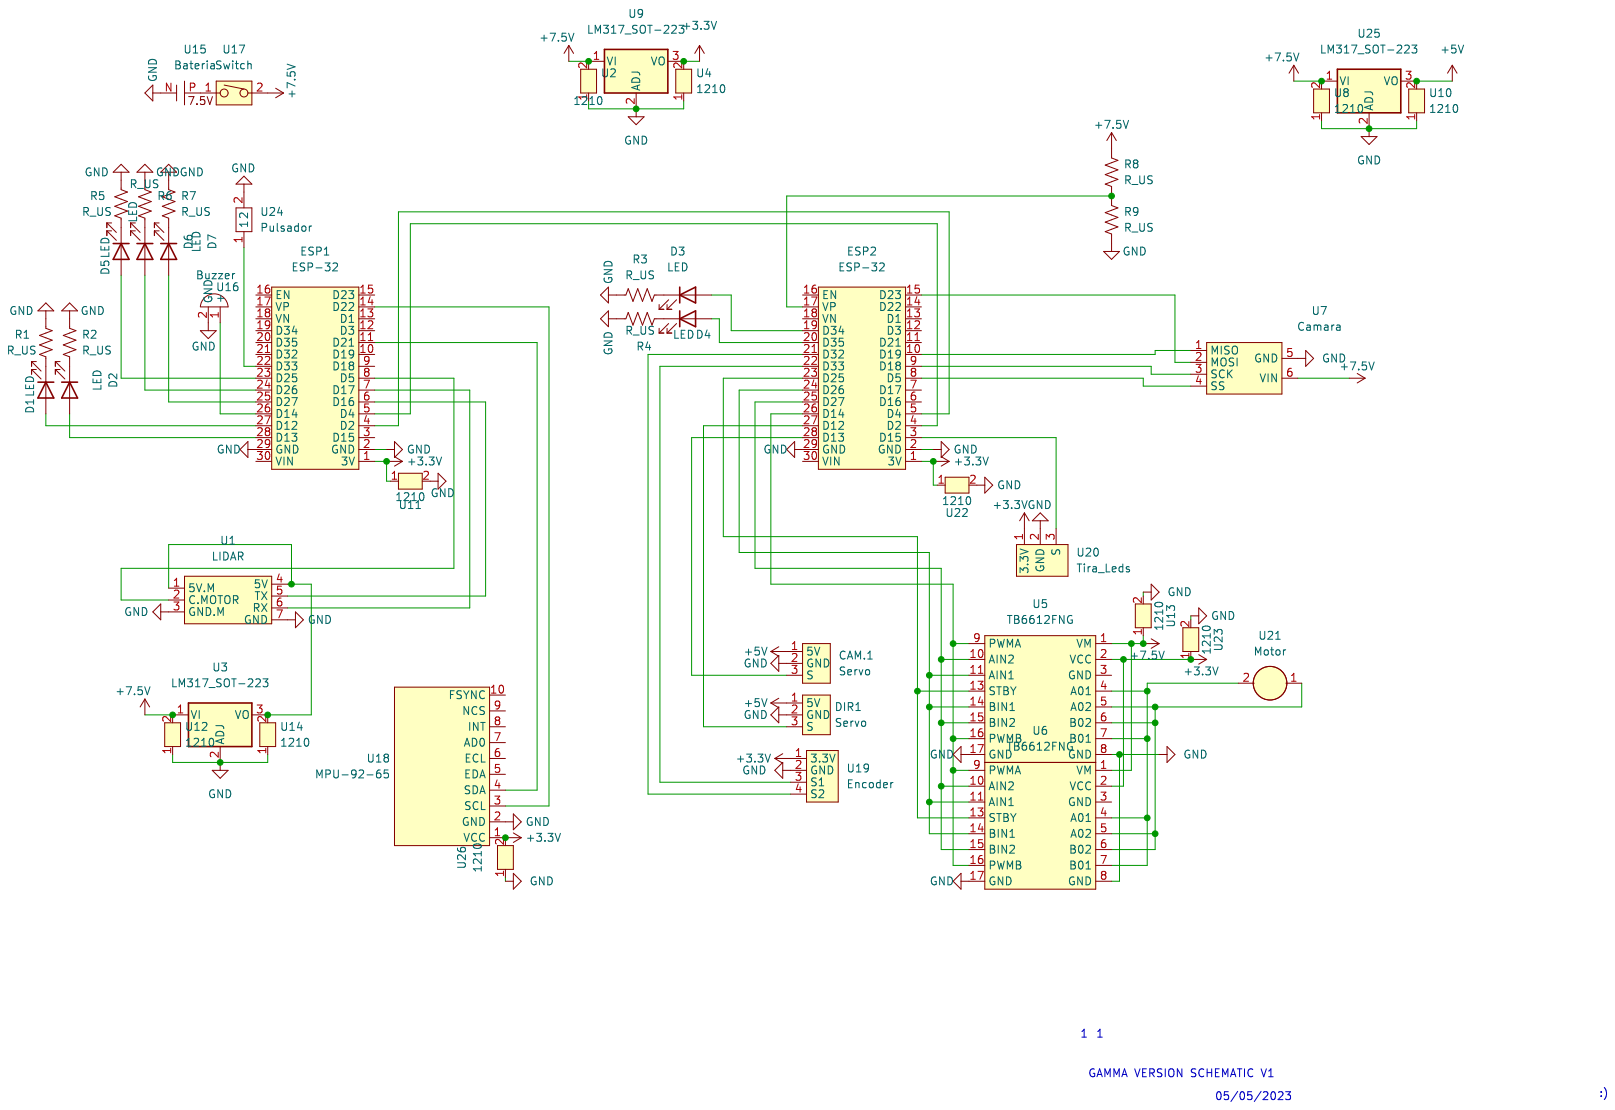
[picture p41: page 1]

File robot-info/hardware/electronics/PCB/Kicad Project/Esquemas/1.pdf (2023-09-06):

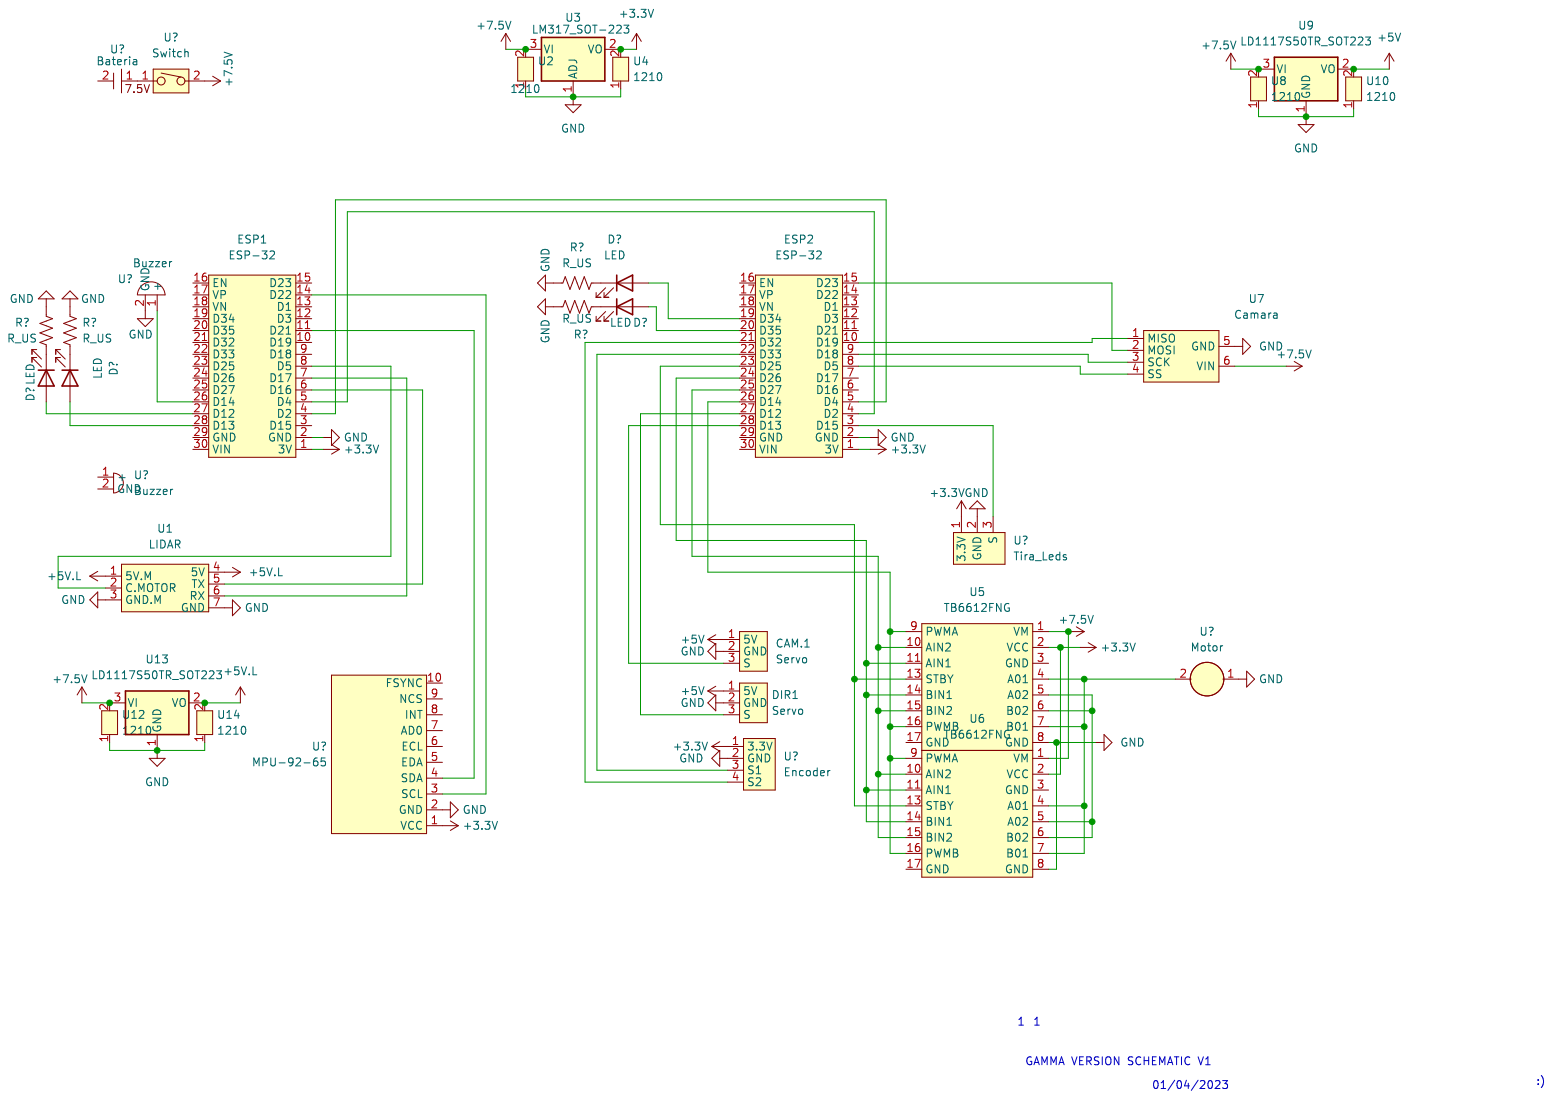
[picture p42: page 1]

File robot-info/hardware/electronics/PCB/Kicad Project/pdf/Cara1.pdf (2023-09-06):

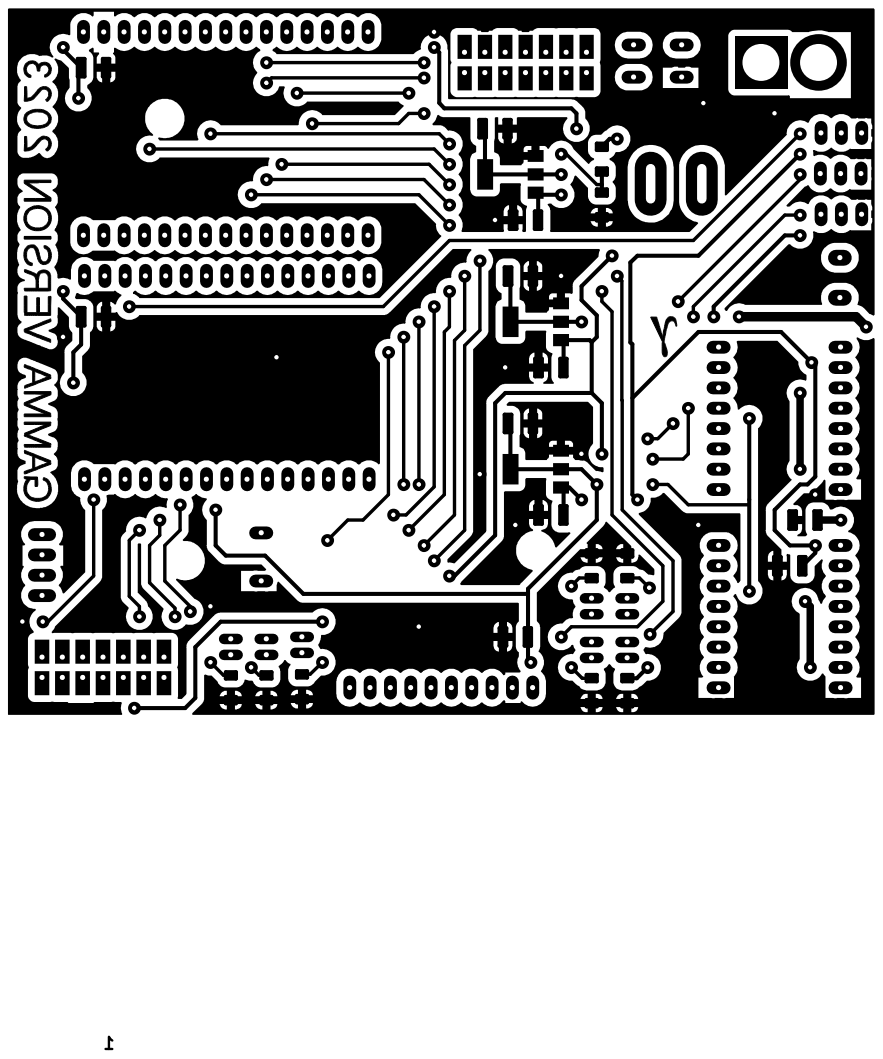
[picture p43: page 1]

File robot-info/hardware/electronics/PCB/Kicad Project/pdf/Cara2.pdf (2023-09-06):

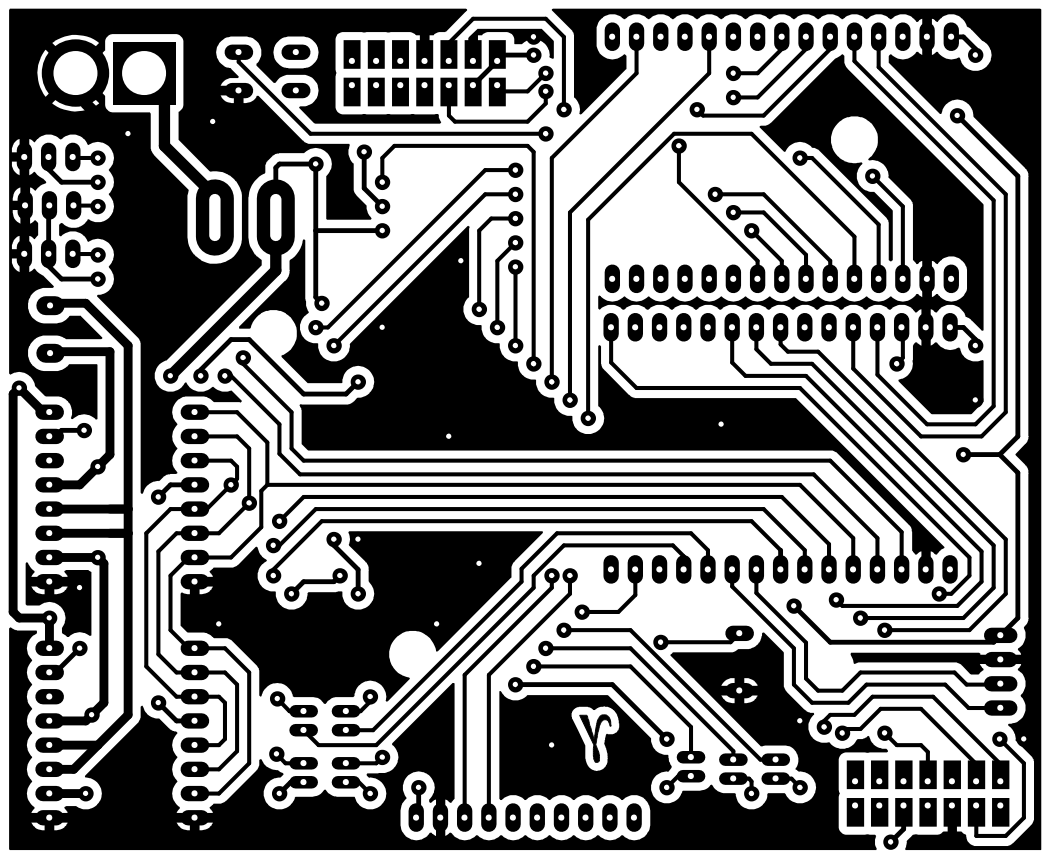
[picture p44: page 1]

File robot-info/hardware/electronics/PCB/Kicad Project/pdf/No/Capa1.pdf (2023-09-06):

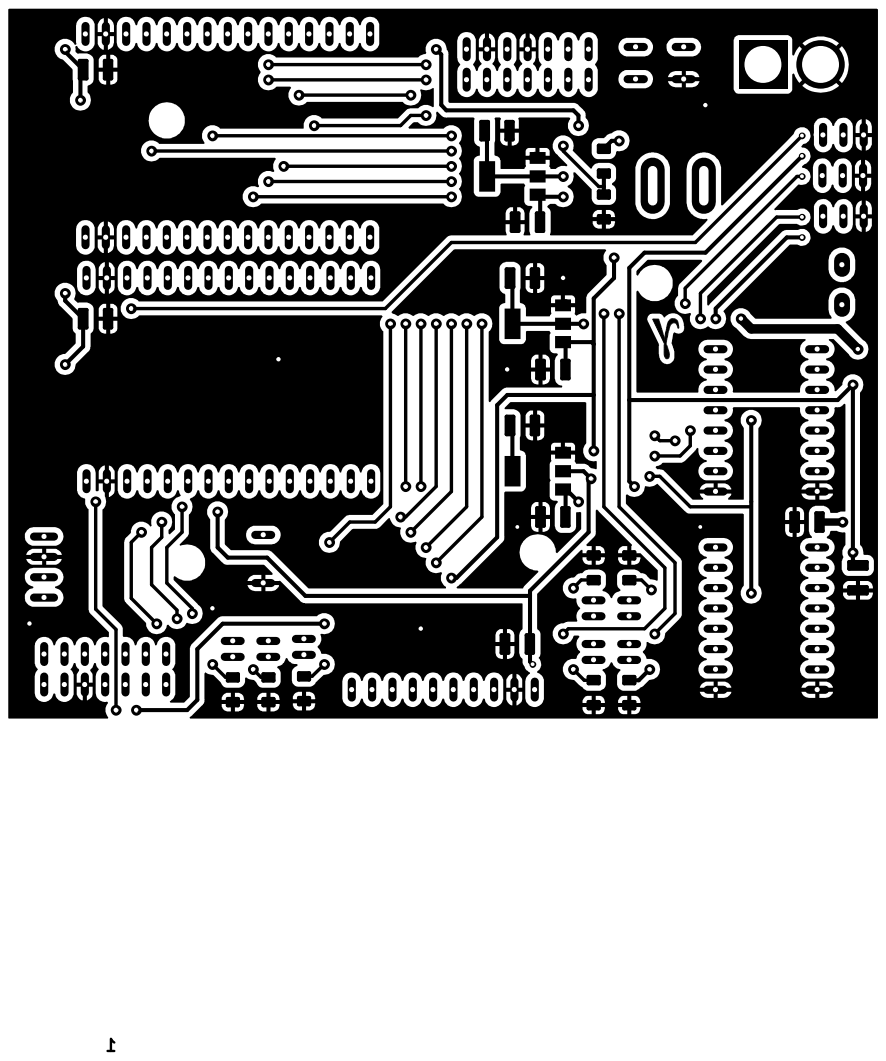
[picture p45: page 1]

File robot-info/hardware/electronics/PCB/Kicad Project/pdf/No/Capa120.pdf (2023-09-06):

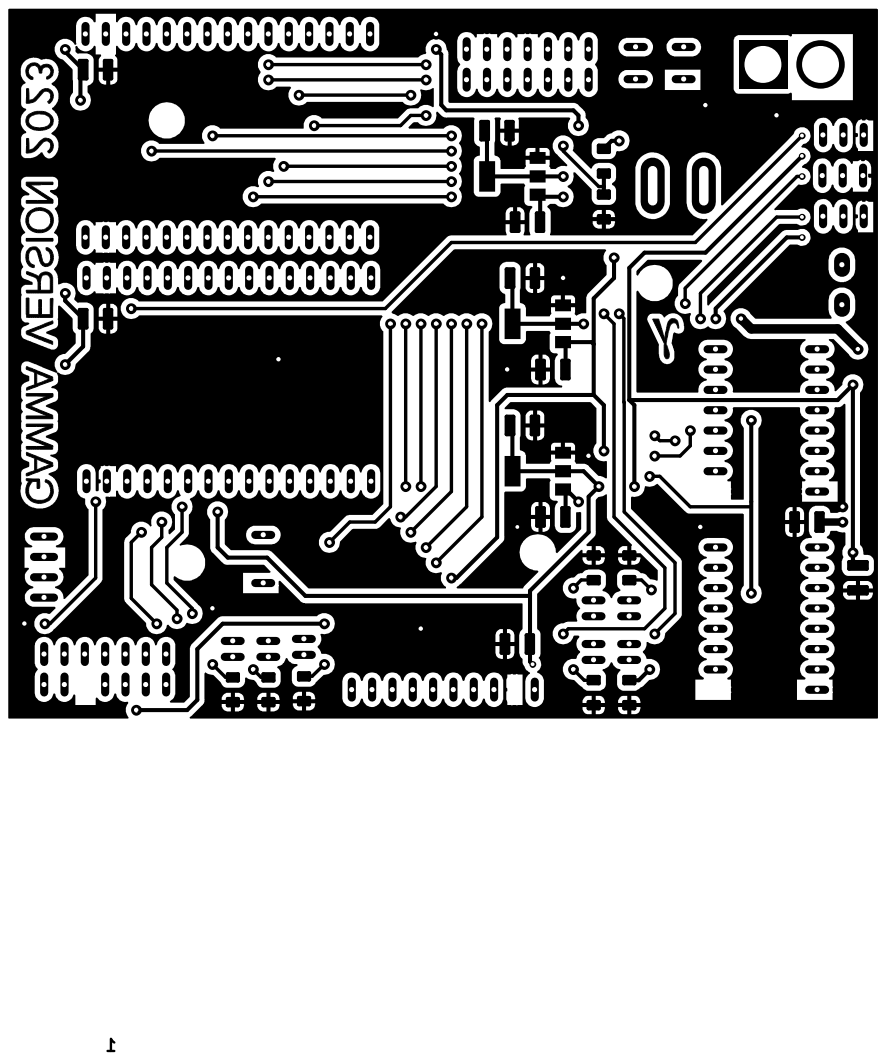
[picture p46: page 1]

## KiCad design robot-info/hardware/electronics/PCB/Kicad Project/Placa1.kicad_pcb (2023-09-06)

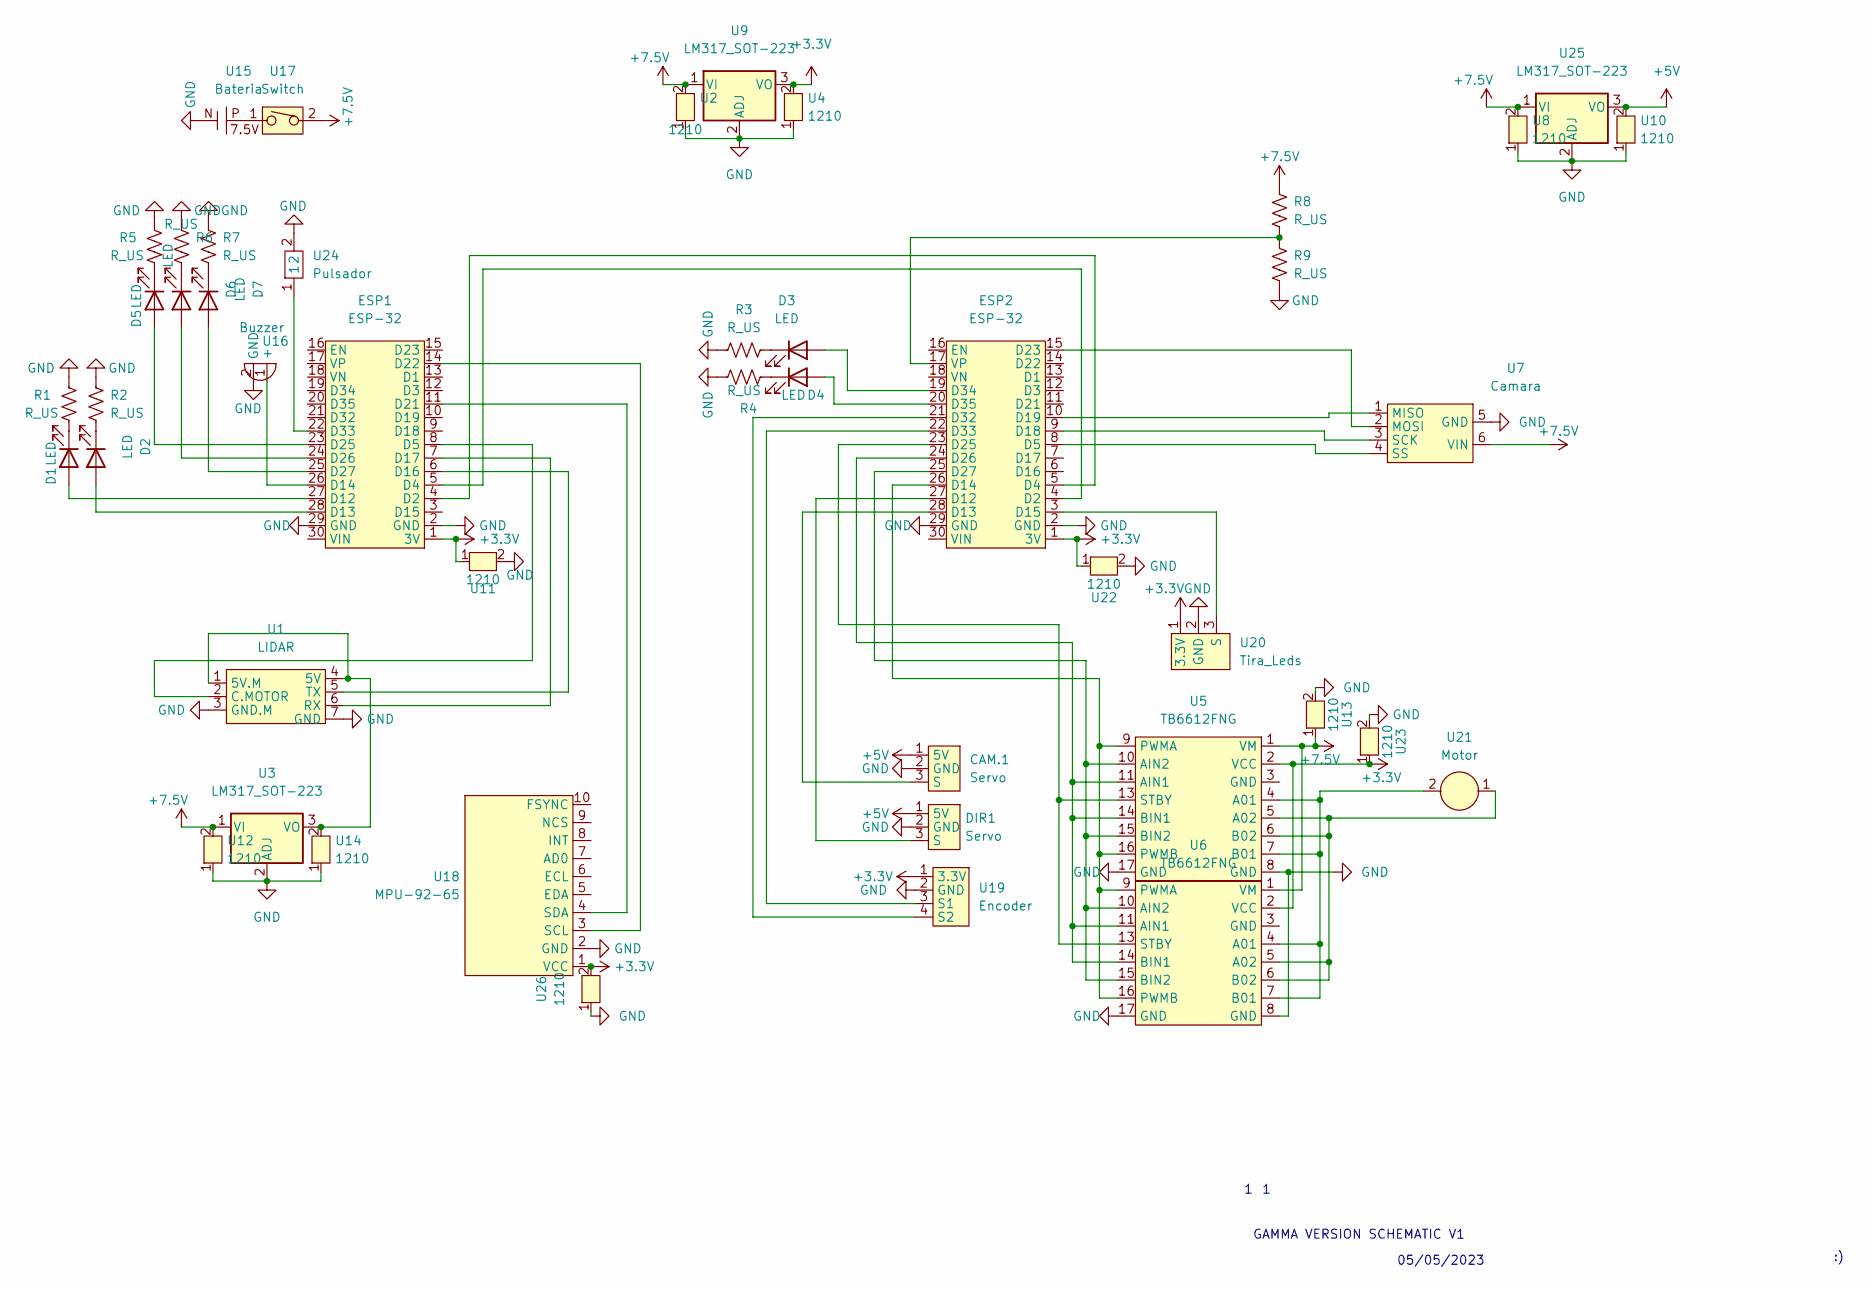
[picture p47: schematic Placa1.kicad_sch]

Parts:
CAM.1: Servo
D1, D2, D3, D4, D5, D6, D7: LED
DIR1: Servo
ESP1, ESP2: ESP-32; ESP32-DEVKITV1Si
R1, R2, R3, R4, R5, R6, R7, R8, R9: R_US; R_1206_3216Metric_Pad1.30x1.75mm_HandSolder
U1: LIDAR; Lidar
U2, U4, U8, U10, U11, U12, U13, U14, U22, U23, U26: 1210; C_1210_3225Metric_Pad1.33x2.70mm_HandSolder
U3, U9, U25: LM317_SOT-223; SOT-223-3_TabPin2
U5, U6: TB6612FNG
U7: Camara
U15: Bateria; AMASS_XT60-M
U16: Buzzer
U17: Switch
U18: MPU-92-65
U19: Encoder
U20: Tira_Leds; Tira
U21: Motor
U24: Pulsador

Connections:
+3.3V: ESP1.1 (3V), ESP2.1 (3V), U4.2, U5.2 (VCC), U6.2 (VCC), U9.3 (VO), U11.1, U18.1 (VCC), U19.1 (3.3V), U20.1 (3.3V), U22.1, U23.1, U26.2
+5V: CAM.1.1 (5V), DIR1.1 (5V), U10.2, U25.3 (VO)
+7.5V: R8.1, U2.2, U3.1 (VI), U5.1 (VM), U6.1 (VM), U7.6 (VIN), U8.2, U9.1 (VI), U12.2, U13.1, U17.2, U25.1 (VI)
GND: CAM.1.2 (GND), DIR1.2 (GND), ESP1.2 (GND), ESP1.29 (GND), ESP2.2 (GND), ESP2.29 (GND), R1.1, R2.1, R3.1, R4.1, R5.1, R6.1, R7.1, R9.2, U1.3 (GND.M), U1.7 (GND), U2.1, U3.2 (ADJ), U4.1, U5.8 (GND), U5.17 (GND), U6.8 (GND), U6.17 (GND), U7.5 (GND), U8.1, U9.2 (ADJ), U10.1, U11.2, U12.1, U13.2, U14.1, U15.N, U16.2 (GND), U18.2 (GND), U19.2 (GND), U20.2 (GND), U22.2, U23.2, U24.2, U25.2 (ADJ), U26.1
unnamed: CAM.1.3 (S), ESP2.28 (D13)
unnamed: D1.1 (K), R1.2
unnamed: D1.2 (A), ESP1.27 (D12)
unnamed: D2.1 (K), R2.2
unnamed: D2.2 (A), ESP1.28 (D13)
unnamed: D3.1 (K), R3.2
unnamed: D3.2 (A), ESP2.19 (D34)
unnamed: D4.1 (K), R4.2
unnamed: D4.2 (A), ESP2.20 (D35)
unnamed: D5.1 (K), R5.2
unnamed: D5.2 (A), ESP1.23 (D25)
unnamed: D6.1 (K), R6.2
unnamed: D6.2 (A), ESP1.24 (D26)
unnamed: D7.1 (K), R7.2
unnamed: D7.2 (A), ESP1.25 (D27)
unnamed: DIR1.3 (S), ESP2.27 (D12)
unnamed: ESP1.4 (D2), ESP2.5 (D4)
unnamed: ESP1.5 (D4), ESP2.4 (D2)
unnamed: ESP1.6 (D16), U1.5 (TX)
unnamed: ESP1.7 (D17), U1.6 (RX)
unnamed: ESP1.8 (D5), U1.2 (C.MOTOR)
unnamed: ESP1.11 (D21), U18.4 (SDA)
unnamed: ESP1.14 (D22), U18.3 (SCL)
unnamed: ESP1.22 (D33), U24.1
unnamed: ESP1.26 (D14), U16.1 (+)
unnamed: ESP2.3 (D15), U20.3 (S)
unnamed: ESP2.8 (D5), U7.4 (SS)
unnamed: ESP2.9 (D18), U7.3 (SCK)
unnamed: ESP2.10 (D19), U7.1 (MISO)
unnamed: ESP2.15 (D23), U7.2 (MOSI)
unnamed: ESP2.17 (VP), R8.2, R9.1
unnamed: ESP2.21 (D32), U19.4 (S2)
unnamed: ESP2.22 (D33), U19.3 (S1)
unnamed: ESP2.23 (D25), U5.13 (STBY), U6.13 (STBY)
unnamed: ESP2.24 (D26), U5.11 (AIN1), U5.14 (BIN1), U6.11 (AIN1), U6.14 (BIN1)
unnamed: ESP2.25 (D27), U5.10 (AIN2), U5.15 (BIN2), U6.10 (AIN2), U6.15 (BIN2)
unnamed: ESP2.26 (D14), U5.9 (PWMA), U5.16 (PWMB), U6.9 (PWMA), U6.16 (PWMB)
unnamed: U1.1 (5V.M), U1.4 (5V), U3.3 (VO), U14.2
unnamed: U15.P, U17.1
unnamed: U5.5 (A02), U5.6 (B02), U6.5 (A02), U6.6 (B02), U21.1
unnamed: U5.4 (A01), U5.7 (B01), U6.4 (A01), U6.7 (B01), U21.2

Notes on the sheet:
05/05/2023
GAMMA VERSION SCHEMATIC V1

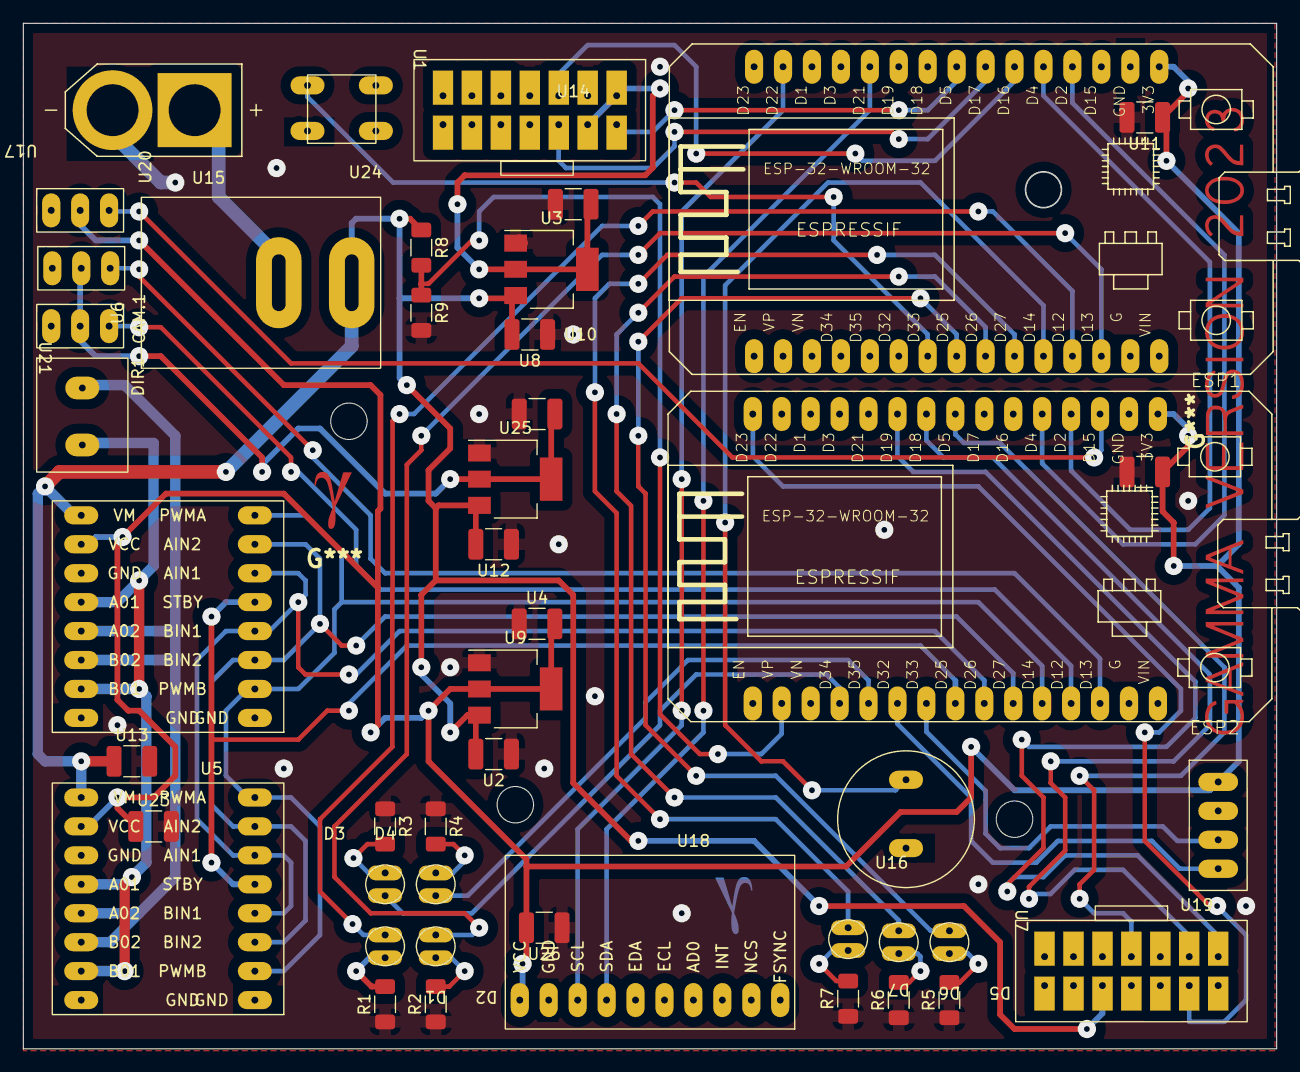
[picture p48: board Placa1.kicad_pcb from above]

Board: 2 copper layers, 110.0 x 90.0 mm, 46 parts (0 on the bottom side), 45 nets.

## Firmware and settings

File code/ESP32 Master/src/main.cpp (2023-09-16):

#include <Arduino.h>
#include <AdvancedMPU.h>
#include <RPLidar.h>
#include <melody_factory.h>
#include <melody_player.h>
#include "credentials.h"
#include "pinAssignments.h"

// Enables wifi functions when true
#define ENABLE_WIFI false

#if ENABLE_WIFI == true
#include <OTAUpdate.h>
#include <Telemetry.h>

IPAddress receiversIP(192, 168, 0, 102);
uint16_t receiversPort = 4210;
uint16_t udpPort = 1234;
uint16_t otaPort = 80;

Updater miota(otaPort);
TelemetryManager telemetry(receiversIP, receiversPort);
#endif

// Servo and direction variables

#define servoKP 2.5
#define servoKD 0
int prev_setAngle;
int actual_directionError;
int prev_directionError;
float objectiveDirection;

// battery level variable
uint8_t bateria;

// camera signatures

bool firma1Detectada = true;
uint8_t firma1X = 18;
uint8_t firma1Y = 19;
bool firma2Detectada = true;
uint8_t firma2X = 20;
uint8_t firma2Y = 21;

// telemetry (ignore)
uint8_t arrayBloques[8];

// conversion between mm and encoder counts
#define MMperEncoder 1.41

// List of possible states for the car
enum e {
  Inicio,
  Recto,
  DecidiendoGiro,
  PreGiro,
  Girando,
  Final
};
uint8_t estado = e::Inicio;

// journey variables

uint8_t giros = 0;
uint8_t tramo = 0;
int8_t turnSense = 0;

// encoder variables

uint32_t encoderMeasurement;
uint32_t prev_encoderMeasurement;

// lidar measurement variables

uint16_t distances[360];
static uint16_t distancesMillis[360];

// car position on the map (origin at the bottom-left corner)

// x position of the car (increases to the right)
double xPosition = 0;
// y position of the car (increases upwards)
double yPosition = 0;

// position PID controller variables

#define positionKP 0.1
#define positionKD 1
int objectivePosition = 0;
int positionError;
int prev_positionError;
bool fixXposition = true;
bool fixInverted = true;

// object declarations

MPU mimpu;
HardwareSerial lidarSerial(2);
RPLidar lidar;
HardwareSerial commSerial(1);
TaskHandle_t Task1;
HardwareSerial teleSerial(0);
MelodyPlayer player(pinBuzzer, HIGH);
const uint8_t nNotes = 45;
String notes1[nNotes] = 
{
  "A4", "E5", "SILENCE",    "A4", "E5", "SILENCE",    "B4", "E5", "SILENCE",    "B4", "E5", "SILENCE",
  "C4", "E5", "SILENCE",    "C4", "E5", "SILENCE",    "D4", "E5", "SILENCE",    "D4", "E5", "B4",
  "A4", "E5", "SILENCE",    "A4", "E5", "SILENCE",    "B4", "E5", "SILENCE",    "B4", "E5", "SILENCE",
  "C4", "E5", "SILENCE",    "C4", "E5", "SILENCE",    "D4", "E5", "SILENCE"
};
const uint8_t timeUnit = 625;
// create a melody
Melody melody1 = MelodyFactory.load("Cornfield chase", timeUnit, notes1, nNotes);
String notes2[9] = {"D4", "D4", "D4", "D4", "E5", "E5", "E5", "E5", "B4"};
Melody melody2 = MelodyFactory.load("Cornfield chase 2", 156, notes2, 9);
String notes3[60] =
{
  "A4", "C4", "E5", "A5",   "A4", "C4", "E5", "A5",   "A4", "C4", "E5", "A5",
  "B4", "D4", "E5", "B5",   "B4", "D4", "E5", "B5",   "B4", "D4", "E5", "B5",
  "B4", "D4", "E5", "B5",   "B4", "D4", "E5", "B5",   "B4", "D4", "E5", "B5",
  "A4", "C4", "E5", "A5",   "G3", "B4", "E5", "F5",   "A4", "C4", "E5", "A5",
  "B4", "D4", "E5", "B5",   "A4", "C4", "E5", "A5",   "G3", "B4", "E5", "F5"
};
Melody melody3 = MelodyFactory.load("Cornfield chase 3", 156, notes3, 60);
String notes4[18] =
{
  "A5", "E6", "A5",   "A5", "E6", "A5",   "B5", "E6", "B5",   "B5", "E6", "B5",   "C5", "E6", "C5",   "C5", "E6", "C5"
};
Melody melody4 = MelodyFactory.load("Cornfield chase 4", 625, notes4, 18);

// calculate the error in the direction
int directionError(int bearing, int target);

// esp32 intercommunication functions

// set the car's speed
void setSpeed(int speed);
// set the angle of the servo
void setSteering(int angle);
// receive data from the serial
void receiveData();
// turn a led on depending on the tension received
void manageTension(uint8_t tension);

// LIDAR management variables

// get the index in the distances array for an angle given
uint16_t getIndex(float angle);
// Angle from 0 to 359
uint16_t readDistance(uint16_t angle);
// Create code for the task which manages the LIDAR
void LidarTaskCode(void * pvParameters);

// send a piece of data to the telemetry esp32
void enviarDato(byte* pointer, int8_t size);

// functions for the management of the car's position

void iteratePositionPID();  // invoke an iteration of the pid controller for the position
void turn();            // turn
void setXcoord(uint16_t i);   // set the coordinate x axis
void setYcoord(uint16_t f);   // set the coordinate y axis
void decideTurn();  // detect the sense of turn
void checkTurn();   // check wether you have to turn or not

void setup() {
  // put your setup code here, to run once:

  // begin serial
  Serial.begin(115200);
  // begin telemetry serial
  teleSerial.begin(1000000, SERIAL_8N1, telemetriaRX, telemetriaTX);
  // begin esp32 intercommunication serial
  commSerial.begin(1000000, SERIAL_8N1, pinRX, pinTX);

  // set all the pin modes
  setPinModes();

  #if ENABLE_WIFI == true
    miota.WiFiInit();
    miota.SetStaticIP(250);
    miota.OTAInit();

    telemetry.StartUDP(udpPort);
  #endif
  player.play(melody1);
      player.play(melody2);
      player.play(melody3);
      player.play(melody4);
  // configure the mpu
  mimpu.BeginWire(pinMPU_SDA, pinMPU_SCL, 400000);
  mimpu.Setup();
  mimpu.WorkOffset();

  // begin the lidar
  lidar.begin(lidarSerial);
  rplidar_response_device_info_t info;
  while (!IS_OK(lidar.getDeviceInfo(info, 100))) delay(500);
  rplidar_response_device_health_t health;
  lidar.getHealth(health);
  Serial.println("info: " + String(health.status) +", " + String(health.error_code));
  // detected...
  lidar.startScan();

  // Asign lidar Task to core 0
  xTaskCreatePinnedToCore(
    LidarTaskCode,
    "Task1",
    100000,
    NULL,
    10,
    &Task1,
    0);
  delay(500);

  // start lidar's motor rotating at max allowed speed
  analogWrite(pinLIDAR_motor, 255);
  delay(500);

  // wait until y coordinate is calculated
  while (readDistance(0) == 0)
  {
    digitalWrite(pinLED_rojo, HIGH);
  }
  digitalWrite(pinLED_rojo, LOW);
  digitalWrite(pinLED_verde, HIGH);
  setYcoord(readDistance(0));
  digitalWrite(pinLED_verde, HIGH);

  /*
  digitalWrite(pinLED_verde, HIGH);
  while (digitalRead(pinBoton)) {
    while (commSerial.available())
    {
      receiveData();
    }
  }
  digitalWrite(pinLED_verde, LOW);*/
  delay(500);

  // start driving (set a speed to the car and initialize the mpu)
  setSpeed(2);
  mimpu.measureFirstMillis();
}

void loop() {
  // put your main code here, to run repeatedly:

  // receive data from the intercommunication serial
  while (commSerial.available())
  {
    receiveData();
  }

  // update mpu's angle
  mimpu.UpdateAngle();

  // repeat position functions every 32ms
  static uint32_t prev_ms_position = millis();
  if (millis() > prev_ms_position) {
    if (encoderMeasurement != prev_encoderMeasurement) {
      // calculate the increment in position and add it
      double dy = (encoderMeasurement - prev_encoderMeasurement) * cos(mimpu.GetAngle() * (M_PI/180)) * MMperEncoder;
      double dx = (encoderMeasurement - prev_encoderMeasurement) * sin(mimpu.GetAngle() * (M_PI/180)) * MMperEncoder;
      prev_encoderMeasurement = encoderMeasurement;
      xPosition -= dx; // x -> + derecha - izquierda
      yPosition += dy;
      iteratePositionPID();
    }
    prev_ms_position = millis() + 32;
  }

  // send telemetry every 100ms
  static uint32_t prev_ms_tele = millis();
  if (millis() > prev_ms_tele+100)
  {

    /*FORMATO TELEMETRIA
    |inicioTX            |TipoPaquete|Datos|
      0xAA,0xAA,0xAA,0xAA,0x--,0x--...0x--
    */
   /*ENVIAMOS PAQUETE TIPO 4 DISTANCIAS*/
    for(int i = 0; i<4; i++){
      teleSerial.write(0xAA);
    }
    teleSerial.write(04);
    uint16_t zi=0;
    while (zi < 360)
    {
        teleSerial.write(distances[zi]>>8);
        teleSerial.write(distances[zi]&0x00ff);
        zi++;
    }
    /*/ENVIAMOS PAQUETE TIPO 3 CALIDAD MEDIDA/
    for(int i = 0; i<4; i++){   //Enviamos la cabecera de inicio de paquete
      teleSerial.write(0xAA);
    }
    teleSerial.write(03);
    uint16_t pi=0;
    while (pi < 360){
        teleSerial.write(distancesArray[1][pi]);
        pi++;
    }*/

    /*ENVIAMOS PAQUETE TIPO 5 INFORMACION GENERAL*/
                /*
            --Posicion x 8 bytes
            --Posición y 8 bytes
            --Posición x Objetivo 8 bytes
            --Posición y Objetivo 8 bytes
            --Encoder 32 uint32
            --Estado 8bits  uint
            --batería 8bits uint
            --Ángulo 16 float
            --Angulo Objetivo 16 float
            --Cámara firma1 Detectada 1 byte
            --Cámara firma1 x 8 bits
            --Cámara firma1 y 8 bits
            --Cámara firma2 Detectada 1byte
            --Cámara firma2 x 8bits
            --Cámara firma2 y 8bits
            
            |XXXX|YYYY|MMMM|NNNN|QQQQ|W|E|RRRR|TTTT|U|I|O|A|S|D
             0000 0000 0111 1111 1112 2 2 2222 2223 3 3 3 3 3 3
             1234 5678 9012 3456 7890 1 2 3456 7890 1 2 3 4 5 6
            */
    for(int i = 0; i<4; i++){   //Enviamos la cabecera de inicio de paquete
      teleSerial.write(0xAA);
    }
    teleSerial.write(05);
    long posXLong = xPosition;
    long posYLong = yPosition;
    long posXObjLong = objectivePosition;
    long posYObjLong = (turnSense==-1)?1:(turnSense==1)?2:0;
    long anguloLong = mimpu.GetAngle();
    long anguloObjLong = objectiveDirection;
    enviarDato((byte*)&posXLong,sizeof(posXLong));
    enviarDato((byte*)&posYLong,sizeof(posYLong));
    enviarDato((byte*)&posXObjLong,sizeof(posXObjLong));
    enviarDato((byte*)&posYObjLong,sizeof(posYObjLong));
    enviarDato((byte*)&encoderMeasurement,sizeof(encoderMeasurement));
    enviarDato((byte*)&estado,sizeof(estado));
    enviarDato((byte*)&bateria,sizeof(bateria));
    enviarDato((byte*)&anguloLong,sizeof(anguloLong));
    enviarDato((byte*)&anguloObjLong,sizeof(anguloObjLong));
    enviarDato((byte*)&firma1Detectada,sizeof(firma1Detectada));
    enviarDato((byte*)&firma1X,sizeof(firma1X));
    enviarDato((byte*)&firma1Y,sizeof(firma1Y));
    enviarDato((byte*)&firma2Detectada,sizeof(firma2Detectada));
    enviarDato((byte*)&firma2X,sizeof(firma2X));
    enviarDato((byte*)&firma2Y,sizeof(firma2Y));
    enviarDato((byte*)&arrayBloques,sizeof(arrayBloques));
    enviarDato((byte*)&tramo,sizeof(tramo));

    prev_ms_tele = millis();
  }

  // check turn every 50ms
  static uint32_t prev_ms_turn = millis();
  if (millis() > prev_ms_turn) {
    checkTurn();
    prev_ms_turn = millis() + 50;
  }

  // repeat direction pid iterations every 20ms
  static uint32_t prev_ms_direction = millis();
  if (millis() > prev_ms_direction) {
    actual_directionError = constrain(directionError(mimpu.GetAngle(), objectiveDirection), -127, 127);
    int _setAngle = servoKP * actual_directionError + servoKD * (actual_directionError - prev_directionError);
    if(_setAngle != prev_setAngle) {
      setSteering(_setAngle);
      prev_setAngle = _setAngle;
    }
    prev_directionError = actual_directionError;
    prev_ms_direction = millis() + 20;
  }

  // state machine
  switch (estado)
  {
  case e::Inicio:
    if (yPosition >= 2500) {
      decideTurn();
      if (turnSense != 0) {
        setXcoord(readDistance(270));
        objectivePosition = xPosition;
        analogWrite(pinLIDAR_motor, 0);
        estado = e::Recto;
        setSpeed(5);
      }
    }
  break;
  case e::Recto:
    if (giros == 12) {
      estado = e::Final;
      
    }
  break;
  case e::Final:
    if (yPosition >= 1200) {
      setSpeed(0);
    }
  break;
  }
}

int directionError(int bearing, int target) {
  int error = target - bearing;
  return error;
}

void setSpeed(int speed) {
  speed = constrain(speed, -100, 100);
  uint8_t _speed = (abs(speed) << 1) | ((speed >= 0) ? 0 : 1);
  commSerial.write(1);
  commSerial.write(_speed);
}

void setSteering(int angle) {
  angle = constrain(angle, -90, 90);
  uint8_t _angle = angle + 90;
  commSerial.write(2);
  commSerial.write(_angle);
}

void receiveData() {
  uint8_t firstByte;
  commSerial.readBytes(&firstByte, 1);
  if (firstByte == 7) {
    uint8_t bytes[4];
    commSerial.readBytes(bytes, 4);
    encoderMeasurement = 0;
    for (uint8_t iteration; iteration < 4; iteration++) {
      encoderMeasurement = encoderMeasurement | bytes[iteration] << (8*iteration);
    }
  } else if (firstByte == 6) {
    uint8_t tensionValue;
    commSerial.readBytes(&tensionValue, 1);
    bateria = tensionValue;
    manageTension(tensionValue);
  }
}

void manageTension(uint8_t tension) {
  if (tension == 1) {
    digitalWrite(pinLED_batAmarillo, LOW);
    digitalWrite(pinLED_batRojo, LOW);
    digitalWrite(pinLED_batVerde, HIGH);
  } else if (tension == 2) {
    digitalWrite(pinLED_batVerde, LOW);
    digitalWrite(pinLED_batRojo, LOW);
    digitalWrite(pinLED_batAmarillo, HIGH);
  } else if (tension == 3) {
    digitalWrite(pinLED_batVerde, LOW);
    digitalWrite(pinLED_batAmarillo, LOW);
    digitalWrite(pinLED_batRojo, HIGH);
  }
}

uint16_t getIndex(float angle) {
  if (angle >= 359.5) return 0;
  float error = angle - uint16_t(angle);
  if (error < 0.5) {
    return uint16_t(angle);
  } else {
    return uint16_t(angle + 1);
  }
}

// Angle from 0 to 359
uint16_t readDistance(uint16_t angle) {
  int index = -5;
  int validIndex = index;
  int validMeasures[10];

  while (index < 5) {
    // work out the resultant index for the distances array
    int resAngle = angle + index;
    if (resAngle < 0) resAngle += 360;

    // check whether the measurement is non zero and new and store it into the next place of the array
    if (distances[resAngle] == 0) {}
    else if ((millis() - distancesMillis[resAngle]) < 500)
    {
      validMeasures[validIndex] = resAngle;
      validIndex++;
    }

    index++;
  }
  // search for two consecutive measurements that are similar
  for (int arrayIndex = 1; arrayIndex < validIndex; arrayIndex++) {
    if (abs(distances[validMeasures[arrayIndex]] - distances[validMeasures[arrayIndex - 1]]) < 50) {
      return distances[validMeasures[arrayIndex]];
    }
  }
  // if the search fails return 0
  return 0;
}

// Create code for the task which manages the lidar
void LidarTaskCode(void * pvParameters) {
  for (;;) {
    vTaskDelay(1);
    if (IS_OK(lidar.waitPoint())) {
      // record data
      uint16_t distance = uint16_t(lidar.getCurrentPoint().distance); //distance value in mm unit
      float angle    = lidar.getCurrentPoint().angle; //angle value in degrees

      // obtain the index associated with the angle and store in the array
      uint16_t index = getIndex(angle);

      if (distance > 100 && distance < 3000)
      { 
        //bool  startBit = lidar.getCurrentPoint().startBit; //whether this point belongs to a new scan
        //byte quality = lidar.getCurrentPoint().quality;

        distances[index] = distance;
        distancesMillis[index] = millis();
      } else {
        distances[index] = 0;
        distancesMillis[index] = 0;
      }
    }
  }
}

void iteratePositionPID() {
  prev_positionError = positionError;
  if (fixXposition) {
    positionError = directionError(xPosition, objectivePosition);
  } else {
    positionError = directionError(yPosition, objectivePosition);
  }
  objectiveDirection = constrain(positionKP * positionError + positionKD * (positionError - prev_positionError), -90, 90);
  if (fixInverted) objectiveDirection = -objectiveDirection;
  objectiveDirection += 90 * giros * turnSense;
}

void turn() {
  switch ((tramo+1) * turnSense)
  {
  case -1:
    objectivePosition = 2700;
    fixInverted = false;
    tramo = 1;
    break;
  
  case -2:
    objectivePosition = 2700;
    fixInverted = false;
    tramo = 2;
    break;

  case -3:
    objectivePosition = 300;
    fixInverted = true;
    tramo = 3;
    break;

  case -4:
    objectivePosition = 300;
    fixInverted = true;
    tramo = 0;
    break;
  
  case 1:
    objectivePosition = 2700;
    fixInverted = true;
    tramo = 1;
    break;
  
  case 2:
    objectivePosition = 400;
    fixInverted = false;
    tramo = 2;
    break;

  case 3:
    objectivePosition = 400;
    fixInverted = false;
    tramo = 3;
    break;

  case 4:
    objectivePosition = 2700;
    fixInverted = true;
    tramo = 0;
    break;
  }
  giros++;
  fixXposition = !fixXposition;
  firma1Detectada = fixXposition;
}

void setXcoord(uint16_t i) {
  xPosition = i;
}

void setYcoord(uint16_t f) {
  yPosition = 3000 - f - 150;
}

void checkTurn() {
  switch ((tramo+1) * turnSense)
  {
  case -1:
    if (yPosition >= 2700 - 200) turn();
    break;
  
  case -2:
    if (xPosition >= 2700 - 200) turn();
    break;

  case -3:
    if (yPosition <= 300 + 200) turn();
    break;

  case -4:
    if (xPosition <= 300 + 300) turn();
    break;

  case 1:
    if (yPosition >= 2700 - 300) turn();
    break;
  
  case 2:
    if (xPosition <= 300 + 300) turn();
    break;

  case 3:
    if (yPosition <= 300 + 300) turn();
    break;

  case 4:
    if (xPosition >= 2700 - 300) turn();
    break;
  }
}

void decideTurn(){
  if (readDistance(90) > readDistance(270) && readDistance(90) > 1000)
  {
    turnSense = -1;
  }
  else if (readDistance(270) > readDistance(90) && readDistance(270) > 1000)
  {
    turnSense = 1;
  }
  else turnSense = 0;
}

void enviarDato(byte* pointer, int8_t size){
  int8_t posicion = size - 1;   //recorreremos la memoria desde el de mas valor hara el de menos, ya que el 
                          //receptor espera ese orde MSB
  while(posicion >= 0 ){
    teleSerial.write(pointer[posicion]);
    posicion--;
  }
}

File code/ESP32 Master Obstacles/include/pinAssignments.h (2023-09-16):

// LED pins
#define pinLED_rojo 12
#define pinLED_verde 13

// Battery level LED pins
#define pinLED_batRojo 27
#define pinLED_batAmarillo 26
#define pinLED_batVerde 25


// buzzer
#define pinBuzzer 14

// LIDAR pins (UART2 + PWM)
#define pinLIDAR_TX 16
#define pinLIDAR_RX 17
#define pinLIDAR_motor 5

// MPU pins (I2C)
#define pinMPU_SDA 21
#define pinMPU_SCL 22

// Interchip Communication pins (UART)
#define pinTX 2
#define pinRX 4

// Button pin
#define pinBoton 33

// Telemetry serial pins
#define telemetriaTX 19
#define telemetriaRX 23

// Pin Modes
void setPinModes() {
    pinMode(pinBoton, INPUT_PULLUP);
    pinMode(pinLED_rojo, OUTPUT);
    pinMode(pinLED_verde, OUTPUT);
    pinMode(pinLED_batRojo, OUTPUT);
    pinMode(pinLED_batAmarillo, OUTPUT);
    pinMode(pinLED_batVerde, OUTPUT);
    pinMode(pinLIDAR_motor, OUTPUT);
}

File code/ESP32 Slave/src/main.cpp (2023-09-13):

#include <Arduino.h>
#include <Motor.h>
#include <CServo.h>
#include <Encoder.h>
#include <Pixy2.h>
#include "credentials.h"
#include "pinAssignments.h"

#define ENABLE_WIFI fasle
#define ROUND_NUMBER 2

#if ENABLE_WIFI == true
#include <OTAUpdate.h>
Updater miota(80);
#endif

hw_timer_t* timerHandler;

HardwareSerial commSerial(1);
Motor mimotor(pinPWM, pinDir1, pinDir2, pinEn, 0.25, 1);
CServo miservo(pinServo);
Encoder miencoder(pinEncoder_DT);

#if ROUND_NUMBER == 2

#define TAMANO_MINIMO_ESQUIVE 20
#define ALTURA_MINIMA_ESQUIVE 50

Pixy2 pixy;
#endif

volatile int speed;
int objectiveSpeed;

void IRAM_ATTR onTimer();

void receiveData();
void sendEncoder(uint32_t encoder);
void sendTension(uint8_t batteryLevel);
void actualizarBateria();
// Battery levels
// 8.4V - 3600
// 8V - 3300
// 7.6V - 3100

#if ROUND_NUMBER == 2
void sendCamera(uint8_t signature, uint16_t x, uint16_t y);
#endif

void setup() {
  // put your setup code here, to run once:
  Serial.begin(115200);
  Serial.println("Empezando");
  
  setPinModes();

  commSerial.begin(1000000, SERIAL_8N1, pinTX, pinRX);

  #if ENABLE_WIFI == true
  miota.WiFiInit();
  miota.SetStaticIP(251);
  miota.OTAInit();
  #endif
  
  Serial.println("Time: ");
  delay(5000);

  timerHandler = timerBegin(0, 80, true);
  timerAttachInterrupt(timerHandler, &onTimer, false);
  timerAlarmWrite(timerHandler, 32000, true);

  #if ROUND_NUMBER == 2
  pixy.init();
  #endif

  miencoder.Attach(CHANGE);
  mimotor.Init();
  //mimotor.SetPower(40);
  miservo.BeginPWM();
  miservo.Attach();
  miservo.MoveServo(0);
  timerAlarmEnable(timerHandler);
}

void loop() {
  // put your main code here, to run repeatedly:
  
  while (commSerial.available())
  {
    receiveData();
  }

  static uint32_t prev_ms_speed;
  if (millis() > prev_ms_speed) {
    mimotor.SetSpeed(speed, objectiveSpeed);
    prev_ms_speed = millis() + 32;
  }

  static uint32_t prev_ms_bat = millis();
  if (millis() > prev_ms_bat) {
    actualizarBateria();
    prev_ms_bat = millis() + 500;
  }

  static uint32_t prev_ms_encoder = millis();
  if (millis() > prev_ms_encoder) {
    sendEncoder(miencoder.GetEncoder());
    prev_ms_encoder = millis() + 32;
  }

  #if ROUND_NUMBER == 2

  static uint32_t prev_ms_camera = millis();
  if (millis() > prev_ms_camera) {
    pixy.ccc.getBlocks();
    if (pixy.ccc.numBlocks) {
      int tamano = 0;
      int mayor = -1;
      for (uint8_t index = 0; index < pixy.ccc.numBlocks; index++) {
        if (pixy.ccc.blocks[index].m_width > tamano) {
          mayor = index;
          tamano = pixy.ccc.blocks[index].m_width;
        }
      }
      if (tamano >= TAMANO_MINIMO_ESQUIVE) {
        if (pixy.ccc.blocks[mayor].m_y >= ALTURA_MINIMA_ESQUIVE) {
          //Serial.println("tamano: " + String(tamano));
          //Serial.println("y: " + String(pixy.ccc.blocks[mayor].m_y));
          sendCamera(pixy.ccc.blocks[mayor].m_signature, pixy.ccc.blocks[mayor].m_x, pixy.ccc.blocks[mayor].m_y);
        }
      }
    }
    prev_ms_camera = millis() + 100;
  }
  #endif
}

void IRAM_ATTR onTimer() {
  speed = miencoder.GetEncoderInterval();
}

void sendEncoder(uint32_t encoder) {
  uint8_t encoderBuffer[4];
  for (uint8_t i; i<4; i++) {
    encoderBuffer[i] = ((encoder>>(8*i)) & 0xff);
  }
  commSerial.write(7);
  commSerial.write(encoderBuffer, 4);
}

void sendTension(uint8_t batteryLevel) {
  commSerial.write(6);
  commSerial.write(batteryLevel);
}

#if ROUND_NUMBER == 2
void sendCamera(uint8_t signature, uint16_t x, uint16_t y) {
  uint8_t _x = uint8_t(x/2);
  uint8_t _y = uint8_t(y/2);
  commSerial.write(5);
  commSerial.write(signature);
  commSerial.write(_x);
  commSerial.write(_y);
}
#endif

void receiveData() {
  uint8_t firstByte;
  commSerial.readBytes(&firstByte, 1);
  if (firstByte == 1)
  {
    uint8_t _velocity;
    commSerial.readBytes(&_velocity, 1);
    uint8_t _speed = (_velocity >> 1)<<1;
    int speed = (_velocity - _speed) ? -_speed : _speed;
    objectiveSpeed = speed;
  } else 
  if (firstByte == 2)
  {
    uint8_t _angleByte;
    commSerial.readBytes(&_angleByte, 1);
    int _angle = _angleByte - 90;
    miservo.MoveServo(_angle);
  }
}

void actualizarBateria() {
  uint16_t tension = analogRead(pinTension);
  if (tension >= 3300) {
    // HIGH LEVEL
    sendTension(1);
  } else if (tension >= 3100) {
    // MEDIUM LEVEL
    sendTension(2);
  } else {
    // LOW LEVEL
    sendTension(3);
  }
}

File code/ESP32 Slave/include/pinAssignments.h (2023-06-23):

// LED pins
#define pinLED_1 34
#define pinLED_2 35

// Motor Pins (PWM + 3 Digital)
#define pinPWM 14
#define pinDir1 26
#define pinDir2 27
#define pinEn 25

// Servo pin (PWM)
#define pinServo 13

// Encoder pins
#define pinEncoder_CLK 32
#define pinEncoder_DT 33

// Interchip Communication pins (UART)
#define pinTX 4
#define pinRX 2

// Battery tension reader pin
#define pinTension 36

void setPinModes() {
    pinMode(pinTension, INPUT);
    pinMode(pinEncoder_DT, INPUT);
    pinMode(pinEncoder_CLK, INPUT);
}

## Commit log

2023-02-11 LIDAR info
2023-02-11 LIDAR info - fix
2023-02-11 LIDAR info 2
2023-04-09 Base code projects added
    Projects for a principal ESP32 (Master) and a secondary ESP32 (Slave)
2023-04-09 Motor library created
    Not finished, first sketch
    README, Motor.h and Motor.cpp files
    Inspired in the 2022 version
2023-04-09 Motor changes
    Added keywords
    Simple README
    Perfections to the code
2023-04-09 Servo library created
    Simple skecth of the Servo library
2023-04-10 Encoder library created
    Sketch of the library to control an encoder
2023-04-19 Uploaded Simple Electronic Schematic
    Just a conceptual schemetic to obtain a simple idea of the circuit.
2023-04-19 Corrections
    ESP32 Slave platform.ini: lib_ldf_mode set to deep
    MPU: Corrections to the measurement
    Motor: Formating
    OTA README: API Reference
2023-04-22 Added lidar datasheet
2023-06-11 ESP32 Master First code
    Telemetry library created (Not finished)
    OTAUpdate library included
    Pin assignations declared
    lidar, mpu and ota test
2023-06-11 ESP32 Slave First Code
    Pin assignations delcared
    Encoder test
    Motor, servo and ota test
    battery tension test
2023-06-15 Update models
    [CameraSupport-Base.stl, CameraSupports.FCStd, EncoderSupport-Axis.stl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]
2023-06-23 ESP32 Slave Updated
    gitignore updated
    pinAssignments.h created
    Encoder library: getEncoder method added
    otaUpdate library: staticIP method added
    README.md created
    main.cpp updated:
    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
2023-07-14 Stage 1 almost complete
2023-07-21 Update
    Slave: Encoder sending rate higher
2023-07-25 ESP32 Telemetry updated
2023-09-06 Folders moved
    [CameraSupport-Base.stl, CameraSupports.FCStd, EncoderSupport-Axis.stl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]
2023-09-06 Wheel vibration solved
2023-09-06 ESP32 Master Obstacles created
    Project for phase 2 created.
    Copied from Phase 1.
2023-09-06 ESP32 Master Obstacles created
    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
2023-09-07 Camera added to ESP32 Slave
2023-09-07 Pixy filters size
2023-09-07 7-9-2023 20:07
    [FrontBumper.stl]
2023-09-07 Revert "7-9-2023 20:07"
    This reverts commit 845503dcec27ac46d311f6a57b603cb1a1d1470b.
    [FrontBumper.stl]
2023-09-07 Documentation update
    Added Unity telemetry project.
    Added video demonstration urls.
    models and electronics moved to hardware.
    [CameraSupport-Base.stl, CameraSupports.FCStd, EncoderSupport-Axis.stl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]
2023-09-07 07/09/2023 21:00
    Phase 2 almost completed.
    Camera detects color blocks.
    Car follows paths.
2023-09-08 PHASE 2 OBSTACLES AVOIDED
    [main.cpp]
2023-09-09 added track constants
2023-09-13 camera support
    [CameraSupport.stl]
2023-09-16 16/09/2023 17:26
    Access point & telemetry fix
    Music for some reason
    [main.cpp, pinAssignments.h]
